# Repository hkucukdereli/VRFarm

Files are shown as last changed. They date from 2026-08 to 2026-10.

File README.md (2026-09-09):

# VRFarm

A behavioural neuroscience rig for head-fixed mice: visual stimuli on a rear-projected
curved screen, capacitive lick detection, calibrated liquid reward, a running wheel,
behaviour video, and photodiode sync — all driven from a browser on the controller.

One rig is two Raspberry Pis. The **Leader** runs the trial loop and every behavioural
device; the **Follower** does nothing but render the projector. The **Controller**
(your Mac/Linux box) hosts two Flask UIs, streams live events, and stores the data.
Rigs are named after cheese.

<p align="center">
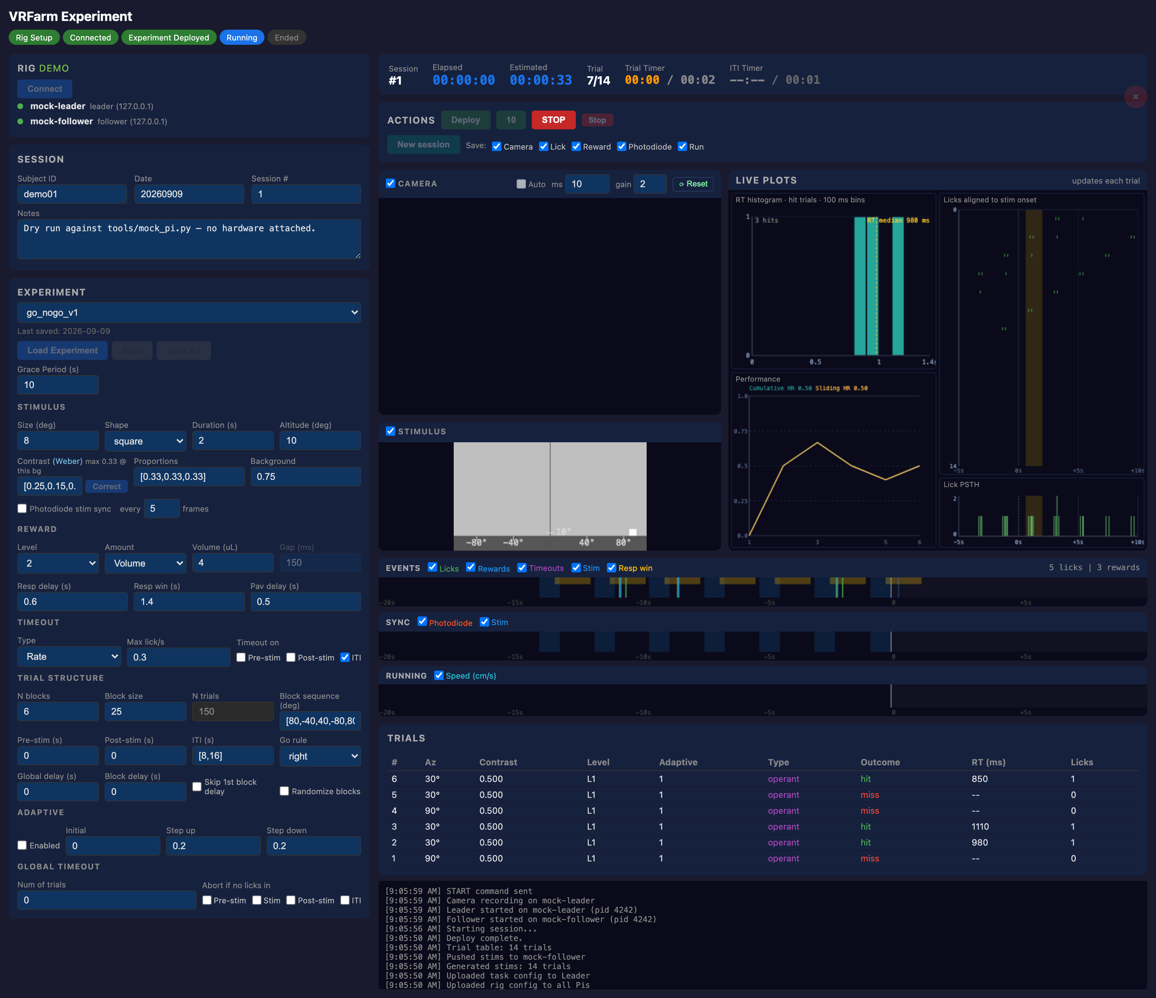
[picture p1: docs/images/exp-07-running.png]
The VRFarm experiment UI during a running session
  
</p>

---

## How it fits together

```
Controller ── controller UI :5000   one app, four tabs: Network · Setup · Experiment · Data
           │                       (build and service rigs, run sessions, watch live, sync data)
                │
                │  REST :5080   deploy code, init devices, camera
                │  UDP  :5572 → START / STOP / REWARD
                │  UDP  :5571 ← trial, lick, reward, stim, sync
                ▼
        Leader Pi ──────────────────────────────────────────────┐
        engine/leader.py: ITI → pre-stim → stim → response       │ UDP :5575
        delay → response window → post-stim, writing HDF5        │ SHOW / QUIT
        lick · reward · camera · photodiode · encoder            ▼
                                                          Follower Pi
                                                    displayd: KMS daemon, renderer
                                                    child draws from a pre-built NPZ
```

Three ideas carry most of the design:

- **Devices are plug-in.** One file in `devices/` declares its I/O type, its packages,
  its tunable parameters and how it writes HDF5. Adding hardware does not touch the engine.
- **Config is split by lifetime.** Hardware facts (pins, calibration, IPs) live in
  `rigs/*.yaml`; the paradigm lives in `experiments/*.yaml`; subject and session are typed
  in at run time. Nothing machine-specific is committed.
- **Stimuli are precomputed.** The Leader builds the whole session's stimulus plan up
  front — geometry warp and luminance correction included — so the Follower only has to
  look up a trial and blit it.

---

## Quick start

Already-built rig, controller already set up:

```bash
conda activate vrfarm
python controller/app.py   # -> http://localhost:5000 (Network / Setup / Experiment / Data)
```

Then, in the Experiment tab: **Load rig → Connect → Load Experiment → fill in
Subject/Date/Session # → Deploy → GO**. At the end of the day the **Data** tab syncs the
sessions off the leaders (Sync Now, or Sync & Poweroff) — see [MULTI_RIG.md](docs/MULTI_RIG.md).
Walkthrough with screenshots:
[Experiment UI](docs/EXPERIMENT_UI.md).

**No hardware?** The whole stack runs on loopback:

```bash
python tools/mock_pi.py     # fake Pi + fake leader
python controller/app.py    # Experiment tab -> Load rig demo -> Connect -> Deploy -> GO
```

**New machine or new rig?** Start at [CONTROLLER_SETUP.md](docs/CONTROLLER_SETUP.md),
then [INITIAL_SETUP_REFERENCE.md](docs/INITIAL_SETUP_REFERENCE.md).

---

## Documentation

| Guide | For |
|---|---|
| **[Docs index](docs/README.md)** | Everything, organised by task |
| [Controller setup](docs/CONTROLLER_SETUP.md) | New controller: network, SSH, conda, data dir |
| [Rig bring-up reference](docs/INITIAL_SETUP_REFERENCE.md) | New/reflashed Pi, envs, GPIO, projector, systemd |
| [Setup UI](docs/SETUP_UI.md) | Defining a rig, deploying code, servicing Pis |
| [Experiment UI](docs/EXPERIMENT_UI.md) | Running a session, live plots, transfer |
| [Experiment protocol](docs/EXPERIMENT_PROTOCOL.md) | Pre-session checks, task parameters, timing |
| [Calibration protocol](docs/CALIBRATION_PROTOCOL.md) | Warp map, luminance, reward valve |
| [Data format](docs/DATA_FORMAT.md) | HDF5 layout and the analysis loaders |
| [Leader wiring](docs/LEADER_WIRING.md) | Pins, 40-pin header map, GPIO rules |
| [Teensy instructions](docs/TEENSY_INSTRUCTIONS.md) | Photodiode sync firmware: build, flash, tune |
| [Rig health monitor](shepherd/README.md) | shepherd: what it watches, thresholds, alerts |

---

## Repo layout

```
controller/    the one controller UI (Flask + SSE)  localhost:5000 — Network / Setup / Experiment / Data
engine/        leader.py (trial loop)                -> runs on the Leader Pi
displayd/      KMS display daemon + renderer child      -> runs on the Follower Pi
devices/       one file per device type + the Device base class
pi_api/        REST API deployed to each Pi (port 5080) + systemd unit
shared/        config loaders, stimulus generator, HDF5 consolidation, notifications
rigs/          rig hardware configs (demo.yaml runs with no hardware)
experiments/   task/paradigm YAMLs
teensy/        photodiode sync firmware (.ino) flashed with arduino-cli
display_calibration/   projector geometry, warp map, luminance fitting
display_diagnostics/   bench tools for the sync square and projector colour
shepherd/      rig health watchdog that runs on a Pi (temperature, disk, CPU, encode rate)
analysis/      HDF5 loaders and analysis notebooks
tools/         mock_pi.py (hardware-free harness) · capture_ui_shots.py (doc screenshots)
docs/          documentation (docs/images generated; docs/assets is local-only)
```

## Requirements

**Controller** — Python 3.11 conda env `vrfarm`:
`flask requests scipy matplotlib numpy h5py pyyaml`

**Pis** — Debian 13 (trixie), conda env `rig` whose Python **must match the system
Python**, because the camera and GPIO bindings are apt-built and symlinked in. GPIO is
`lgpio` (no daemon; works on Pi 4 and Pi 5). Per-device packages are installed for you by
the setup UI's **Install**.

Optional: `VRFARM_SLACK_WEBHOOK` for session start/end/timeout notifications;
`VRFARM_DATA_DIR` to put session data somewhere other than `~/VRFarm/data`.

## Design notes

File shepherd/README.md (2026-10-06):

# shepherd — VRFarm rig health monitor

A tiny, **out-of-process** watchdog that runs on a rig Pi and watches the things
that can silently ruin a session: SoC temperature and throttling, disk space,
CPU/memory, the camera's live encode rate, and whether `pi_api` is still answering.

## Why a separate process

The Pi 5 has **no hardware H.264 encoder and no fan**, so a long session software-
encodes on the CPU and heats up. When it throttles, the encoder slows, **drops
frames, and corrupts the frame timing** the whole camera pipeline exists to
preserve — and none of that is visible in the preview or in the data until you
analyse it. shepherd catches it live.

A monitor living *inside* `pi_api` would freeze at exactly the moment you most
want its data (a thermal stall, a wedged process). shepherd runs in its own
process, so a stall or crash in `pi_api` can't take the watchdog down with it —
and shepherd's API probe is precisely what **detects** that stall.

It is deliberately minimal: each cycle is a few `/proc` and `/sys` reads plus one
short HTTP probe. Sampling cost is far below anything it watches. It **does not
stream telemetry**, does not touch the HDF5, and writes only two plain files.

## What it watches

| Metric | Source | Default warn / critical |
|---|---|---|
| SoC temperature | `/sys/class/thermal` | 50 °C / 70 °C |
| Throttle / under-voltage flags | `vcgencmd get_throttled` | soft-limit / throttling-now |
| Disk used % (video mount) | `statvfs` | 80% / 90% |
| Disk free GB | `statvfs` | 40 / 15 GB |
| Total + per-core CPU | `/proc/stat` | 85% / 95% |
| Memory used % | `/proc/meminfo` | 85% / 95% |
| Disk write rate | `/proc/diskstats` | off by default |
| Camera encode fps (while recording) | `pi_api /api/status` | 45 / 30 fps |
| `pi_api` responsive | HTTP probe | critical once down past the [grace period](#pi_api-grace-period); at once during a session |

Every threshold, direction, and **message** is editable in `~/rig/shepherd/config.yaml` on the leader
(seeded from [`config_template.yaml`](config_template.yaml)).

## Two alert levels

- **warning** → orange in the experiment-UI log
- **critical** → red in the UI log, **and** a Slack message (so it reaches you with
  the browser closed)

One exception: `soc_temp_c` is **muted on the Slack hop only**. A fanless Pi crosses the
70 °C critical routinely under camera encode, so it paged constantly without naming an
action. It still logs to the UI and to `alerts.log` at full level, and the `throttled`
metric — which reports that heat actually cost you frames — still pages. The mute list is
`_SLACK_MUTED_SHEPHERD_METRICS` in `controller/events.py`, i.e. controller-side: no rig deploy needed
to change it.

Alerts are **edge-triggered** — fired when a metric changes level, not every
second — so the log isn't spammed. A still-critical condition re-alerts every
`realert_critical_s` (default 30 s). A return to normal logs a recovery line.

Delivery: a `shepherd_alert` UDP packet to the controller's event port
(`network.event_port`, default 5571). The controller already forwards every event
to the UI over SSE; `controller/events.py` adds the Slack hop for criticals (to that rig's own
webhook) and
`experiment.html` colours the line by level. If no session UI is live the packet is
simply dropped (UDP is best-effort) — criticals still reach Slack.

## Outputs (both under `output_dir`, default `~/shepherd_logs/`)

- `shepherd_<timestamp>.jsonl` — one JSON object per sample (all metrics). A plain,
  separate file; **nothing goes into the session `.h5`.**
- `shepherd_<timestamp>.alerts.log` — human-readable warning/critical/recovery lines.

## Running it

**Installed automatically on the leader.** The setup-UI **Install** deploys
`shepherd.py`, seeds `config.yaml` (see below), and installs + enables + starts the
`shepherd` systemd service. It then runs continuously, learning session state from
the API probe — you do **not** start/stop it per session. Watch it with:
```bash
journalctl -u shepherd -f
sudo systemctl status shepherd
```

**Config is seeded once, then owned by the Pi.** Install copies the repo's `shepherd/config_template.yaml` to
`~/rig/shepherd/config.yaml` with `cp -n` (no-clobber), so thresholds/messages you edit on the leader survive a
re-Install or Deploy. To change them:
```bash
nano ~/rig/shepherd/config.yaml         # on the leader
sudo systemctl restart shepherd         # shepherd reads the file once at startup
```
(The repo only tracks the template. A `shepherd.py` *code* change rides Deploy, and
Deploy restarts shepherd so the change takes effect.)

**Manually (for a quick look or a test):**
```bash
python3 shepherd/shepherd.py --config shepherd/config_template.yaml
python3 shepherd/shepherd.py --config shepherd/config_template.yaml --once   # one sample, then exit
```

## pi_api grace period

Deploy and **Restart API** restart `pi_api` on purpose, and it answers nothing for a few seconds
while systemd respawns it. So `api_health` does not alert on the first failed probe:

- **Outside a session** it waits out a grace period. The controller times every Deploy / Restart
  API restart (`controller/pi_restart.py`) and writes the measured outage ×1.5, kept within
  5–60 s, to `api_grace.json` next to `config.yaml` (through pi_api's `/api/shepherd_grace`).
  shepherd re-reads the file whenever it changes. Until the first timed restart,
  `api_probe.grace_default_s` (10 s) applies.
- **During a session** (the last good probe said the engine was running) it alerts on the first
  failed probe: nothing restarts pi_api on purpose mid-session, and a crash there takes the engine
  with it.

The Deploy log shows both numbers, e.g. `pi_api on cheddar was down 4.1 s` and
`shepherd on cheddar now gives pi_api 6.2 s to come back before alerting`.

## Configuring

Edit `~/rig/shepherd/config.yaml` on the leader and restart shepherd (it reads the file once at
startup). Each metric block:
```yaml
soc_temp_c:
  enabled: true
  direction: high            # 'high' fires when value rises; 'low' when it falls
  warn: 50
  critical: 70
  warn_msg:     "SoC temperature {value}°C — running warm; check ventilation"
  critical_msg: "SoC temperature {value}°C — CRITICAL: thermal throttle imminent"
  recover_msg:  "SoC temperature back to normal ({value}°C)"
```
Message placeholders: `{value}`, `{warn}`, `{critical}`, `{unit}`, `{mount}`
(and `{error}` for `api_health`).

Point the alerts at your controller:
```yaml
shepherd:
  alerts:
    udp: { enabled: true, host: 192.168.10.1, port: 5571 }
```

## Dependencies

stdlib + PyYAML only. The API probe uses `urllib` (stdlib), not `requests`. Runs in
the `rig` conda env with nothing extra to install.

## Notes / limits

- `vcgencmd` and the thermal zones are Pi-only; off a Pi those metrics are simply
  absent (shepherd degrades gracefully, never errors).
- Live encode fps needs `pi_api /api/status` to expose `camera_frames` (added
  alongside this monitor). Older API builds just omit that one alert.
- The disk write-rate meter sums whole-disk devices matching `disk_devices`; it's a
  coarse "is something hammering the disk" signal, off by default.

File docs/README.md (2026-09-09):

# VRFarm documentation

Everything here is task-shaped: find the row that matches what you are trying to do.
Project overview and repo layout are in the [root README](../README.md).

## Start here

| I want to… | Read |
|---|---|
| Set up a **new controller** machine (network, SSH, conda, data dir) | [CONTROLLER_SETUP.md](CONTROLLER_SETUP.md) |
| Bring up a **new or reflashed Pi**, or build a rig from scratch | [INITIAL_SETUP_REFERENCE.md](INITIAL_SETUP_REFERENCE.md) |
| Understand the **two UIs** before touching anything | [SETUP_UI.md](SETUP_UI.md) · [EXPERIMENT_UI.md](EXPERIMENT_UI.md) |

## Run experiments

| I want to… | Read |
|---|---|
| Run a session end to end, and know what to check first | [EXPERIMENT_PROTOCOL.md](EXPERIMENT_PROTOCOL.md) |
| Find a button, or work out why one is greyed out | [EXPERIMENT_UI.md](EXPERIMENT_UI.md) |
| Understand reward levels, timeouts, task YAML fields | [EXPERIMENT_PROTOCOL.md § Task Parameters](EXPERIMENT_PROTOCOL.md#task-parameters) |
| Load and analyse the data afterwards | [DATA_FORMAT.md](DATA_FORMAT.md) |

## Maintain the rig

| I want to… | Read |
|---|---|
| Add a device, change pins, deploy code, service a Pi | [SETUP_UI.md](SETUP_UI.md) |
| Calibrate the reward valve, projector geometry, or luminance | [CALIBRATION_PROTOCOL.md](CALIBRATION_PROTOCOL.md) |
| Look up geometry parameters | [display_calibration/geometry_params.md](../display_calibration/geometry_params.md) |
| Check wiring, pins and the 40-pin header map | [LEADER_WIRING.md](LEADER_WIRING.md) |
| Build, flash or tune the **Teensy** photodiode sync firmware | [TEENSY_INSTRUCTIONS.md](TEENSY_INSTRUCTIONS.md) |
| Watch rig health during a session (temperature, disk, encode rate) | [shepherd/README.md](../shepherd/README.md) |

## Map of the system

```
Controller  (controller/app.py :5000 — Network / Setup / Experiment / Data tabs)
  │  REST 5080  ─ deploy, config, device init, camera
  │  UDP  5572 →  START / STOP / REWARD
  │  UDP  5571 ←  trial, lick, reward, stim, sync events
  ▼
Leader Pi (engine/leader.py) ── trial loop + lick, reward, camera, photodiode, encoder
  │  UDP 5575 → SHOW / QUIT
  ▼
Follower Pi (displayd) ── KMS daemon; renderer child is sole DRM master on the DLP projector
  │  UDP 5573 → stim_onset / hb_flash acks, display_health
  ▲
```

## Conventions

- **Rig YAML** (`rigs/*.yaml`) holds hardware facts: pins, I²C addresses, calibration
  tables, Pi roles and IPs, ports. Edited in the setup UI.
- **Task YAML** (`experiments/*.yaml`) holds the paradigm in four sections — `stimulus`,
  `reward`, `session`, `adaptive`. Edited in the experiment UI.
- **Machine-specific paths** are never in YAML: the controller data root comes from
  `$VRFARM_DATA_DIR`, else `~/VRFarm/data`.
- All timestamps are `time.time()` Unix seconds, NTP-synced across all three machines.

## Screenshots

UI images live in `docs/images/` and are generated, not hand-taken:

```bash
python tools/capture_ui_shots.py            # all of them
python tools/capture_ui_shots.py --only exp-07
```

The script starts `tools/mock_pi.py` and both UIs on loopback and drives them with
Playwright (`pip install playwright && playwright install chromium`). Re-run it after any
UI change so the docs do not drift. Shots needing real hardware — a live camera frame, the
projector, the geometry landmark tool — must still be taken on the rig.

> `docs/assets/` is a **local-only** stash (audits, hardware design notes, vendor manuals)
> and is gitignored — nothing in the tracked docs links to it.

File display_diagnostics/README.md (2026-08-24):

# display_diagnostics — projector / photodiode bring-up tools

Standalone optical diagnostics for the **follower / display Pi** (mozzarella). They drive
the projector directly so you can check the display→photodiode→scope path and DLP colour
before trusting the real sync pipeline. **pygame**, mirroring `devices/display.py`'s
fullscreen setup by copy — no UDP, no engine, no devices framework, they write no data.
These are kept (not scratch): re-run them on the next rig bring-up. Sibling of
`display_calibration/` (geometry/warp), which owns the calibration side.

The photodiode itself is a GPIO input on **cheddar** (leader, GPIO24) — `devices/photodiode.py`.
These tools only exercise the *optical* side (display → photodiode → your scope); tape the
diode over the sync patch.

## Tools

| File | What it does |
|---|---|
| `sync_square_flash.py` | Flashes the red sync square (matches `display._draw_sync_square`): steady or per-frame pulse, single bottom-centre patch or a bottom-row sweep, colour compare. Photodiode bring-up + mounting-spot sweep. |
| `dlp_color_test.py` | Pushes full-frame / split solid colours (R/G/B/dark, left-right splits) — DLP colour-wheel / brightness-uniformity check. |
| `run_sync_flash.sh` | scp `sync_square_flash.py` to mozzarella and run it on kmsdrm (put displayd in STANDBY first: `curl -sX POST :5581/standby`). Args pass straight through. |

## sync_square_flash.py

Cycles `[ 10 s blank ] → [ 5 s stim ] → repeat`. During the stim it draws a centre stimulus
square plus the red sync square; during the blank both are background gray. Every stim ON/OFF
edge prints a `time.time()` stamp so you can line the scope trace up to the software clock.

**Layout** — `--row N`: by default one red square at bottom-center (matches the real rig).
`--row N` instead draws N evenly-spaced red squares edge-to-edge along the bottom (first
flush-left, last flush-right, so the corners are included), numbered on screen and all pulsing
together. Sweep the diode along the row to choose a mounting spot and to check DLP brightness /
color-wheel uniformity across the screen width.

**Timing** — two modes:

| mode | flag | what the patch does |
|---|---|---|
| steady (default) | — | red for the whole 5 s stim → one rising + one falling edge per cycle |
| pulse | `--pulse N` | replicates the real per-frame sync (`follower._show_synced`): patch ON every Nth frame during the stim. At 60 Hz, `--pulse 5` ≈ a 12 Hz, 1-frame-on train |

### Run it

Projector X must be up (`start_projector.sh` on mozzarella; `run_sync_flash.sh` runs it if needed).

From the Mac:

```bash
cd display_diagnostics
./run_sync_flash.sh --row 7              # bottom-row sweep: 7 squares, find the diode spot
./run_sync_flash.sh --row 7 --pulse 5    # sweep with the real per-frame cadence
./run_sync_flash.sh                      # single bottom-center square (matches the real rig)
./run_sync_flash.sh --color white        # compare red vs white edge on the scope
./run_sync_flash.sh --blank 8 --stim 4 --cycles 5
```

Or directly on mozzarella:

```bash
SDL_AUDIODRIVER=dummy /usr/bin/python3 sync_square_flash.py
```

`ESC` / `q` / `Ctrl-C` quits.

### Options (`sync_square_flash.py --help`)

`--blank` (10) · `--stim` (5) · `--pulse` (0=steady) · `--row` (0=single) · `--no-labels` ·
`--color` red/white/green/blue · `--sync-size` (40) · `--stim-size` (200) ·
`--contrast` (1.0) · `--bg-gray` (0.0) · `--res` (1920 1080) · `--refresh` (60) ·
`--cycles` (0=forever)

## dlp_color_test.py

Loops a pipe-separated colour sequence — each block is `SPEC,...:COUNT`, where SPEC is a full
colour (`red`) or a left/right split (`red/black`) and COUNT is `N` frames or `Ns` seconds.
Default: full R, G, B, dark (1 s each), then half-R, half-G, half-B. Use it to eyeball DLP
colour-wheel behaviour and brightness uniformity.

```bash
SDL_AUDIODRIVER=dummy /usr/bin/python3 dlp_color_test.py
... dlp_color_test.py --seq "red:1s | red/black:1s"   # full then split
... dlp_color_test.py --cycles 20                     # stop after 20 loops
```

Headless projector, so to stop a backgrounded run: `pkill -9 -f 'dlp_color_test[.]py'`.

## Colour note (background)

The real sync square is **red** (`display._draw_sync_square` → `(255,0,0)`). A broadband
photodiode over a red patch on a mid-gray background sees a *smaller* flux change than it looks
(red sums to 255 vs gray's 381), and on a DLP the single red channel is chopped by the colour
wheel — so the edge can read weak or even inverted. **This was resolved:** `devices/display.py`
now draws the sync pulse **red-on-BLACK** (`display.py` `_show_synced` / the forced pre-warp
patch), which triggers reliably. To reproduce that here, run `sync_square_flash.py --bg-gray -1`
(black background). `--color white` is still handy to sanity-check the scope against a maximal edge.

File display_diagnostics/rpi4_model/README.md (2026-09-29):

# Raspberry Pi 4 B + Joy-IT Armor Case "BLOCK" — simplified 3D model

The follower Pi as it sits on the rig: a Raspberry Pi 4 Model B inside the Joy-IT passive
aluminium cooler **RB-AlucaseP4+07 "Armor Case BLOCK"** (finned top block + bottom plate, four
M2.5 socket-head screws from below). Boxes and cylinders only; the board, its four holes and all
connector positions are exact from the Raspberry Pi drawing, the case envelope is Joy-IT's, and
the case details are estimated from photos and flagged below.

| File | What |
|---|---|
| `rpi4b_joyit_armor_case_simplified.step` | assembly STEP, one named solid per part |
| `rpi4b_joyit_armor_case_simplified.stl` | mesh |
| `rpi4b_joyit_armor_case_simplified_iso.svg` | isometric line drawing |
| `rpi4b_joyit_armor_case_hole_maps.png` | top view and stack-up side view with the holes |
| `rpi4_armor_case_dims.py` | **the numbers**, with a `CASE_ESTIMATED` block to check with calipers |
| `build_model.py`, `plot_hole_maps.py` | CadQuery build, matplotlib drawing |

## Frame

Raspberry Pi drawing convention: **X** along the 85 mm edge, 0 at the microSD end, 85 at the
USB/Ethernet end · **Y** along the 56 mm edge, 0 at the USB-C/HDMI/audio edge, 56 at the GPIO
edge · **Z** up, 0 = PCB bottom, 1.4 = PCB top. Envelope about 90 × 57 × 27 mm including the
microSD card, the USB/Ethernet overhang and the estimated 3 mm gap under the block.

## Holes

The assembly has exactly four fixing points: the Pi's mounting holes. Both case halves use them.

| # | Type | Position (X, Y) | Used by |
|---|---|---|---|
| 4 | Ø2.7 through the PCB (M2.5 clearance), 58 × 49 pattern, 3.5 from the edges | (3.5, 3.5), (61.5, 3.5), (3.5, 52.5), (61.5, 52.5) | Joy-IT M2.5 socket-head screws from below, through the bottom plate and the PCB, into threaded posts in the top block |

No other hole is published for either case half. To mount the cased Pi, replace the four screws
with longer M2.5 screws through your bracket under the 3.5 mm bottom plate, or clamp the plate.
Confirm on the part that the plate has no extra holes before designing around that.

## Exact vs estimated

**Exact (Raspberry Pi mechanical drawing):** outline 85 × 56, corner radius 3.0, holes, connector
centres (USB-C x 11.2, micro-HDMI x 26.0 and 39.5, Ethernet y 45.75, USB stacks y 27 and 9, GPIO
header centre x 32.5), component heights above the board (USB-C 3.2, HDMI 3.0, audio 6.0, header
8.5, Ethernet 13.5, USB 16.0, SoC 2.4, FPC connectors 5.5). Connector protrusion past the board
edge is a typical value, ±0.5 mm.

**Published by Joy-IT:** top block 69 × 56 × 15.5, bottom plate 87 × 56 × 7.5, 107 g, CNC-milled
aluminium, four screws, allen key, thermal pads.

**Estimated from photos, measure before relying on it** (`CASE_ESTIMATED` in the dims file):
the block starts at the microSD edge and stops at x = 69, leaving the USB/Ethernet end open; block
underside 3.0 mm above the PCB top; ten grooves along X, 5.0 mm pitch, 2.6 wide, 9 deep; an open
slot over the GPIO header (x 6.5…58.5) and a slot over the camera connector; a pocket along the
front edge clearing the audio jack; Ø6 threaded posts at the holes; bottom plate 3.5 thick with
Ø6 × 4.0 bosses; M2.5 × ~25 socket-head screws with counterbored heads.

If the case on the rig is the closed **RB-AlucaseP4+08** box (91 × 65 × 34, cast, milled channels)
instead, say so: it is a different model, not a parameter change.

## Regenerate

```bash
~/cadenv/bin/python build_model.py            # same venv as ../projector_model (pip install cadquery)
conda activate vrfarm && python plot_hole_maps.py
```

## Sources

- Raspberry Pi 4 Model B mechanical drawing, `datasheets.raspberrypi.com/rpi4/raspberry-pi-4-mechanical-drawing.pdf`
- Joy-IT RB-AlucaseP4+07 product page, datasheet (published 2020-02-11) and manual, `joy-it.net/en/products/RB-AlucaseP4+07`

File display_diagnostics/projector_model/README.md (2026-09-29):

# DLPDLCR230NPEVM — simplified 3D model and hole map

A simplified, parametric model of the projector every VRFarm follower drives: the TI **DLP
LightCrafter Display 230NP EVM** (formatter board DLP038 + Young Optics FLA12-F engine on TI's
sheet-metal base). Boxes and cylinders only, but every part sits at TI's coordinates and every
screw hole is at TI's position, diameter and type. Made for designing mounts and enclosures.

| File | What |
|---|---|
| `dlpdlcr230npevm_simplified.step` | assembly STEP, one named solid per part, coloured |
| `dlpdlcr230npevm_simplified.stl` | the same as a mesh (viewers, slicers) |
| `dlpdlcr230npevm_simplified_iso.svg` | isometric line drawing |
| `dlpdlcr230npevm_hole_maps.png` | 2D hole maps: bottom, top, back wall, side wall |
| `dlpdlcr230npevm_dims.py` | **the numbers** — every dimension and hole, with what it is for |
| `build_model.py` | CadQuery script that builds and exports the model |
| `plot_hole_maps.py` | matplotlib script for the PNG |

## Frame

TI's own "DLP038" assembly frame, so the numbers can be checked against TI's files:
**X = depth** (lens points to −X, lens front at X = −15.37) · **Y = up** (the assembly stands on
Y = −4.82; PCB top at Y = 32.85) · **Z = width** (40-pin header along the −Z edge). For a Z-up CAD
system rotate −90° about X. Envelope **87.4 (X) × 48.2 (Y) × 81.4 (Z) mm**, matching TI's
assembly drawing (81.40 × 87.96 × 48.17).

## Holes, by part

Threads are listed as TI tapped them; the model draws them at tap-drill size (M1.6 → Ø1.25,
M2 → Ø1.60, M2.5 → Ø2.05), exactly as TI's STEP does. "CSK" = Ø2.90 through + Ø5.50 × 90°
countersink for an M2.5 flat-head screw.

**There is no dedicated external mounting hole on this EVM.** Every hole below is used by a TI
fastener. Bottom-side candidates for a rig mount are the three base tabs (occupied by flat-head
screws you can replace with longer ones), the bracket's wall edges (clamp), or the tapped M2.5/M2
wall holes (occupied; replace screws).

### MCH051 base (1.63 mm aluminium sheet, footprint 69.82 × 77.31, standing plane Y = −4.82)
| # | Type | Axis | Position (mm) | TI use |
|---|---|---|---|---|
| 3 | Ø2.90 through, Ø5.50 90° CSK opening **downward** | Y | (X, Z) = (3.50, 4.77), (51.81, −23.95), (62.31, −23.95) | M2.5 × 5 flat-heads from below into the fan-bracket tab (2) and the PCB corner standoff (1) |
| 4 | M2.5 × 0.45 tapped, horizontal | X / Z | back wall X≈70: (Y −0.82, Z −23.95); −Z wall Z≈−63.9: X 12.64 and 57.27 at Y −0.82; +Z wall Z≈13.4: X 57.27 at Y −0.82 | formatter-base wall screws (M2.5 × 5 flat-heads, CSK on the bracket) |
| 3 | M1.6 × 0.35 tapped | Y | (10.76, −42.42), (39.06, −39.72), (39.06, −15.22) | engine to base (M1.6 × 12 socket heads) — table only, inside the simplified cutout |

### MCH053 formatter base (2.05 mm L-bracket, 78.10 × 81.40, walls Y −4.82…22.83, flange top Y = 24.88)
| # | Type | Axis | Position (mm) | TI use |
|---|---|---|---|---|
| 3 | M2.5 × 0.45 tapped, top flange | Y | (X, Z) = (3.50, −35.50), (16.84, −60.26), (60.40, −51.74) | PCB: M3 6 mm spacer + M2.5 × 10 screw |
| 2 | M2 × 0.4 tapped, top flange | Y | (49.11, 3.73), (66.11, 3.73) | PCB: M3 5 mm spacer + M2 × 12 screw |
| 6 | M2 × 0.4 tapped, walls, all at Y = 20.46 | X / Z | back wall: Z 1.37, −51.92 · front short wall: Z −48.25 · −Z wall: X 57.28, 12.62 · +Z short wall: X 57.28 | (TI: 8× M2 total with the two above) |
| 4 | Ø2.90 + Ø5.50 CSK on the **outer** face, all at Y = −0.80 | X / Z | back wall: Z −23.96 · −Z wall: X 57.28, 12.62 · +Z short wall: X 57.28 | M2.5 × 5 flat-heads into the base's tapped wall holes |

### MCH052 fan bracket (1.63 mm) — fan 25 × 25 × 10 at X 44.5…69.6, Z −42.1…−32.0
| # | Type | Axis | Position | TI use |
|---|---|---|---|---|
| 4 | M2 × 0.4 tapped | Z | (X, Y) = (57.07 ± 10, 9.76 ± 10), 20 × 20 pattern, Ø24 bore | fan screws |
| 2 | M2.5 × 0.45 tapped, bottom tab | Y | (X, Z) = (51.81, −23.95), (62.31, −23.95) | under the base's two CSK holes |

### DLP038 PCB (70.00 × 72.76 × 2.04, at Y 30.81…32.85, X 0…70, Z −63.73…9.03)
| # | Type | Position (X, Z) | Support underneath |
|---|---|---|---|
| 4 | Ø2.69 (M2.5 clearance) | (3.50, −35.50), (16.84, −60.26), (60.40, −51.74) | M3 6 mm spacers on the flange |
| | | (3.50, 4.77) | M2.5 × 23 hex + M2.5 × 10 M-F standoff column down to the base tab |
| 2 | Ø2.39 (M2 clearance) | (49.11, 3.73), (66.11, 3.73) | M3 5 mm spacers on the flange |

40-pin header J2: X 63.97…69.05, Z −62.85…−12.05 (pin rows at X 65.24 / 67.78, 2.54 pitch), 8.5 mm
tall. Barrel jack: X 0.94…12.94, Z −61.20…−45.95.

### Young Optics FLA12-F engine (body 33.28 × 23.07 × 53.03 at X 7.19…40.46, Y −2.97…20.09, Z −45.90…7.12)
Lens axis at (Y 10.39, Z −11.32), barrel Ø16.9, front hood 30.3 × 15.5 reaching X = −15.37.
Top plate per TI's Figure 5-1 (34.13 × 54.99): **4× Ø1.66** (M2 thread-forming; TI uses M2 × 12
pan heads) at plate coordinates (3.63, 3.54), (31.42, 6.24), (31.42, 30.73), (7.53, 50.64).
The plate's orientation in the assembly frame is inferred (v = 0 at the engine's +Z end); check
against the unit before relying on those four positions. All other holes above are exact.

## Provenance

- **TI TIDM757**, "CAD/CAE Symbol" download on the [TIDA-080009](https://www.ti.com/tool/TIDA-080009)
  page: `DLP038_Mechanical_092420.zip` with MCH051/052/053 drawings and STEP files and the full
  `DLP038 - REVF.STEP` assembly. Positions here were measured on the STEP cylinder faces.
- **TI TIDM755**, assembly drawing "P23 EVM TOP ASSEMBLY" DLP038 rev F (2020-09-24): envelope and
  the fastener BOM quoted in `dlpdlcr230npevm_dims.py`.
- **TI DLPU103B**, DLP LightCrafter Display 230NP EVM User's Guide, Figure 5-1: engine drawing.

TI's files are licensed for use in development with TI parts and may not be redistributed, so
they are **not** in this repo — download them from the link above. The 81 × 87 mm "business card"
size on TI's product page is the bracket footprint, not the PCB (70.00 × 72.76).

## Regenerate

```bash
python -m venv ~/cadenv && ~/cadenv/bin/pip install cadquery      # ~1.8 GB, once; keep out of vrfarm
cd display_diagnostics/projector_model
~/cadenv/bin/python build_model.py                                # STEP + STL + SVG
conda activate vrfarm && python plot_hole_maps.py                 # PNG
```
Edit numbers only in `dlpdlcr230npevm_dims.py`; both scripts read from it.

## Simplifications

Sheet-metal bends, reliefs and slots, the base's exact tab outlines, the DMD flex tab, LED cables,
the FPD-Link connector and small components are omitted. Walls and flanges are full-length boxes.
The engine is a box with the lens barrel and the three LED heat sinks; its internal features are not
modelled.

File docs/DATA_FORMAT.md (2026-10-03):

# VRFarm session data format

**`format_version: 2`** — a transferred session is **one self-contained HDF5 file** plus the raw video.

```
<dest>/<subject>/<subject>_<date>/<session_id>/
├── <session_id>.h5     # everything: trials, running wheel, stimulus plan, per-device data, camera timestamps, metadata
└── video.h264          # raw H.264 elementary stream (only if the camera was saved)
```

`session_id = <subject>_<YYYYMMDD>_<NNN>` (e.g. `mouse1_20260803_001`). `<dest>` is the Browse override, else `$VRFARM_DATA_DIR`, else `~/VRFarm/data`.

---

## How the file is built (at session end)

During a run the Leader writes a **flat** `.h5` (one dataset per field at the root), and the camera/stim generator drop sidecars alongside it:

| sidecar | written by |
|---|---|
| `metadata.yaml` | leader engine (in `_finalize_session`) |
| `stimuli.npz` | stim generator |
| `trials.yaml` | stim generator (human-readable copy of the NPZ) |
| `frame_timestamps.npy` | camera (on the SSD, next to `video.h264`) |

**Consolidation runs at session end, not at Transfer.** The moment the session stops or finishes, the Leader engine's `shutdown()` calls `_consolidate_at_exit()` — after every device is closed and its sidecar flushed (the camera's `frame_timestamps.npy` included) — which runs [`shared/consolidate.py`](../shared/consolidate.py) on the just-closed `.h5`. So the archive is already self-contained before anything is transferred. **Transfer re-POSTs `/api/consolidate/<session_id>` as a no-op safety net**, so a session whose exit consolidation didn't run (crash, hard stop) still gets consolidated when pulled.

`consolidate.py`:

1. Reorganizes the flat root datasets into groups (`/trials`, `/lick`, `/reward`, `/photodiode`). Any dataset not in its map — **including the running-wheel arrays** — falls through to `/trials`.
2. Folds `metadata.yaml` into **root attributes**.
3. Folds `stimuli.npz` into **`/stimulus`**, dropping fields already recorded in `/trials` (no redundancy).
4. Folds `frame_timestamps.npy` into **`/camera/frame_timestamps`**.
5. Deletes all four sidecars (`trials.yaml` is redundant with the NPZ).

It's **idempotent** (a file already at `format_version 2`, or that already has a `/trials` group, is left alone) and **atomic** (writes a temp file, then swaps). Only `<session>.h5` + `video.h264` are then pulled to the controller.

---

## File structure

```
<session_id>.h5
├─ (root attrs)          session metadata + full task_config
├─ /trials/              recorded per-trial columns + the continuous running-wheel stream
├─ /stimulus/            pre-generated plan (per-trial arrays + scalar group-attrs)
├─ /lick/                (only if lick_sensor was saved)
├─ /reward/              (only if reward was saved)
├─ /photodiode/          (only if photodiode was saved)
└─ /camera/              (only if the camera was saved)
```

### Root attributes — session metadata
| attr | notes |
|---|---|
| `session_id`, `subject_id`, `date`, `session_num`, `notes` | session identity |
| `level`, `rig_name`, `timestamp` | paradigm level, rig, Unix time of finalize |
| `n_trials_completed`, `n_trials_planned` | trial counts |
| `saved_devices`, `skipped_devices` | which devices' detailed data was recorded. `camera` moves to `skipped_devices` when `camera_saved` is false; sessions recorded before that flag existed list `camera` as saved even when no video was taken |
| `camera_requested`, `camera_saved` | bools sent by the controller at START: Camera was checked at GO / the camera Pi confirmed recording started. **Absent = unknown** (sessions before these existed). A session with `camera_saved: true` and no video on the leader shows as **missing** in the Data tab and is never purged |
| `task_config` | **the entire task YAML as a JSON string** — full paradigm reconstruction |
| `format_version` | `2` |

### `/trials/` — recorded per-trial data (length = `n_trials_completed`)
| dataset | dtype | meaning |
|---|---|---|
| `trial_num`, `block_num` | i4 | indices |
| `trial_outcome` | str | `"hit"` / `"miss"` |
| `level_effective` | f4 | level actually run (adaptive 2.5 → the drawn 2 or 3) |
| `adaptive_state` | f4 | P(L3) for adaptive 2.5, else 1 |
| `stim_az_deg` | f4 | stimulus azimuth (as run) |
| `contrast` | f4 | raw value in the configured metric (what the UI showed) |
| `corr_contrast` | f4 | stimulus **brightness** rendered (0..1 of the intensity calibration's uniform range; may exceed 1). Before the light model (2026-10) it was the normalized headroom fraction |
| `iti_duration_s` | f4 | **actual** ITI before this trial |
| `iti_start_t`, `stim_onset_t`, `true_onset_t`, `response_window_t`, `outcome_t`, `first_lick_t` | f8 | event times (Unix s, NTP-synced) |
| `display_latency_s` | f8 | `true_onset_t − stim_onset_t` (photodiode-measured) |
| `sync_ok` | i1 | 1 if the online photodiode onset-sync landed that trial |
| `trial_run_distance_cm` | f4 | distance the running wheel turned during this trial (cm) |

`true_onset_t` is the display onset corrected by the photodiode; `stim_onset_t` is when the Leader sent SHOW.

#### Running-wheel stream — also under `/trials/`, but length = **number of encoder samples**, not per-trial
The AS5600 wheel encoder is a *continuous* device: it streams for the whole session, so these arrays are far longer than the per-trial columns above (tens of thousands of samples). They share the `/trials` group only because the engine writes them as root datasets and they fall through `consolidate.py`'s group map. They are **not** part of the per-trial `Session.trials` table (different length) — read them from `Session.running` (see Loading) or h5py directly.

| dataset | dtype | meaning |
|---|---|---|
| `running_t` | f8 | sample time (Unix s, NTP-synced — same timebase as `/trials` events) |
| `running_counts` | i8 | **cumulative signed raw encoder counts — the ground truth.** 4096 counts/rev (12-bit AS5600); rotations = `counts / 4096` |
| `running_distance_cm` | f4 | cumulative distance = rotations × wheel circumference (π · `wheel_diameter_cm`) |
| `running_speed_cms` | f4 | instantaneous speed = d(distance)/dt |

Because `running_counts` is the raw ground truth, **speed and distance can be fully recomputed offline** — even with a corrected wheel diameter.

### `/stimulus/` — the pre-generated plan (de-duplicated vs `/trials`)
Per-trial arrays (length = `n_trials_planned`), plus block arrays:
| dataset | meaning |
|---|---|
| `stim_alt_deg` | stimulus altitude/elevation |
| `px_x`, `px_y`, `px_size` | on-screen pixel position + size |
| `duration_s` | planned visual stimulus duration |
| `prestim_s`, `poststim_s` | planned pre/post-stim periods |
| `iti_planned_s` | planned ITIs (length n+1: leading + between + trailing) |
| `block_delays`, `block_start_indices` | per-block delay + first-trial index |
| `stim_brightness`, `stim_lum` | stimulus brightness and requested light (calibration units) |
| `stim_drive`, `contrast_measured` | drive at the stimulus centre; contrast of light delivered there (after any clipping) |

Scalar params as **group attributes**: `background_gray` (a brightness), `bg_lum` (its light), `intensity_calibration` (file whose light model was used), `light_unit`, `shape`, `global_delay`, `block_delay_skip_first`, `sync_square_every_n`.

> Dropped as redundant with `/trials` (recorded): `trial_idx`, `block_num`, `stim_az_deg`, `contrast`, `corr_contrast`, `bg_gray`, `n_trials`.

### `/lick/`, `/reward/`, `/photodiode/` — per device (present only if saved)
| group | datasets |
|---|---|
| `/lick/` | `lick_times` (vlen f8, in-trial), `iti_lick_times` (vlen f8), `iti_lick_count` (i4) |
| `/reward/` | `reward_t` (f8), `reward_amount_ul` (f4, commanded µL), `reward_pavlovian` (i1, 1 = Pav-delay rescue) |
| `/photodiode/` | `sync_pulses` (vlen f8 — rising-edge times) |

Unchecked (skipped) devices → their group is simply **absent** (see `skipped_devices`). Core `/trials` data is always written. The running-wheel **encoder has no group of its own** — its per-trial and continuous data live under `/trials` (above).

### `/camera/frame_timestamps` — video frame timing (present only if saved)
`N×3` float64, with a `columns` attribute:
| column | meaning |
|---|---|
| `frame_idx` | index into the `video.h264` frames |
| `wall_clock_s` | host wall clock at frame callback (`time.time()`, NTP-synced — **same timebase as all `/trials` events**) |
| `sensor_ts_ns` | hardware `SensorTimestamp` (start of readout) on `CLOCK_BOOTTIME`, ns |

---

## Loading (`analysis/loaders.py`)

Two classes turn the file into tidy pandas DataFrames: **`Session`** (one file) and **`Dataset`** (many, concatenated). Every frame carries `session_id` + `subject_id` columns, so single- and multi-session frames are interchangeable.

```python
from analysis.loaders import Session, Dataset

s = Session(session_dir)          # a session dir OR the .h5 path
s.trials      # one row / completed trial — the analysis-ready wide table (see below)
s.running     # one row / wheel-encoder sample (continuous stream; + rotations column)
s.licks       # one row / lick   (long form: in-trial + ITI, times rel. to onset/window)
s.pulses      # one row / photodiode sync pulse (long form, times rel. to onset)
s.stimulus    # one row / planned trial
s.camera      # one row / recorded video frame (empty if the camera wasn't saved)
s.meta        # dict of root attrs; s.meta["task_config"] is the full paradigm
s.stim_attrs  # scalar /stimulus attrs + block arrays (block_delays, iti_planned_s, …)

ds = Dataset(".../data/HK1")      # dir (recursive *.h5), glob, list of paths, or Session(s)
ds.trials                          # every session's trials stacked, tagged by session_id
ds.add(".../HK1_20260811_001.h5")  # append another session (chainable)
ds.meta                            # one row per session
```

**`s.trials` columns** = the recorded `/trials` per-trial cols, plus merged per-trial device data, planned `/stimulus`, and derived ready-to-plot columns:
- **merged:** `reward_t`, `reward_ul`, `pavlovian`, `n_licks`, `n_iti_licks`, `iti_lick_count`, `n_pulses`, `first_pulse_t`, `trial_run_distance_cm`, and planned `stim_alt_deg`, `px_x/px_y/px_size`, `duration_s`, `prestim_s`, `poststim_s`.
- **derived:** `latency_ms`, `rt_ms` (first lick − response-window open), `reward_lat_ms` (reward − true onset), `first_pulse_lat_ms`, `hit` (bool).

The continuous running-wheel arrays are **not** in `s.trials` (different length) — they're in `s.running`. **Only format_version 2 is supported** (no legacy `.npz`/flat-HDF5 fallback).

---

## Not in the session folder
- **Subject index** `subjects/<subject>.json` (controller-side, at the default data dir) — a running log across the subject's sessions (session_id, date, level, trial counts, block sequence, stim size, contrast values, notes). Written once per transfer.

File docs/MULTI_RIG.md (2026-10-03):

# Multi-rig controller

**Last updated:** 2026-09-08

One controller (the lab's is `fystyk`, an Ubuntu box) runs several rigs from one web app on one port. This page explains what
changed from the two old apps (`app/` experiment UI and `setup/` setup UI), how the four
tabs work, and what the Data tab does to your files.

```bash
conda activate vrfarm
python controller/app.py            # http://localhost:5000  (--port 5055 if macOS AirPlay owns 5000)
```

## The four tabs

- **Network** — the rigs and their Pis. Add a rig (the next free IP pair is suggested:
  .101/.102, .103/.104, …), edit Pi names / IPs / roles / users / devices, rename or delete a
  rig (the YAML moves to `rigs/.trash/`), check every Pi over SSH and the REST API, and make
  **groups** ("super rigs"): a group loads all its rigs at once from the Load menu of Setup and
  Experiment and from the Data tab. The architecture diagram is drawn from the rig YAMLs.
- **Setup** — one sub-tab per loaded rig, each the familiar setup page: Pi cards (Check /
  Install / Deploy / Restart API / Reboot / Shutdown), the device catalog and device cards,
  calibration, Slack and Monitor toggles, Save Rig. Pi identity is edited in Network, not here.
- **Experiment** — one sub-tab per loaded rig, each the familiar experiment page. "Load Rig"
  became **Connect** (still a button: connecting stops leftover processes and re-initializes
  devices on the Pis). Transfer is gone; **New session** returns an ended rig to Connected.
  The Save checkboxes (Camera, Lick, Reward, Photodiode, Run) stay.
- **Data** — syncing, purging and powering off, over SSH only (see below).

Hidden sub-tabs keep running (trial counters keep updating) but pause their camera stream; the
badge on each sub-tab shows the phase, trial count and hit rate. Closing a rig in both Setup
and Experiment unloads it from the controller.

## Do rigs need different ports? No.

The ports on the Pis (5080, 5572, 5573, 5575, 5581, 5582) are opened on each Pi separately, so
four rigs with the same numbers never clash. On the controller only one port is opened, UDP 5571,
once at start-up. Every datagram is sorted by the sender's IP to the rig whose Pi has that IP;
as a backup every leader event also carries a `rig` field (that is how the mock Pis, all at
127.0.0.1, are told apart in the tests). The only thing that must be unique per rig is the IP
pair. Datagrams nobody owns are counted and shown at the bottom of the Network diagram.

## Addresses and switch capacity

Everything shares one flat subnet, `192.168.10.0/24`, with no VLANs:

| Range | Use |
|---|---|
| `.1` | the controller (`controller_ip` in `controller.yaml`; new pairs are derived from its /24) |
| `.101`–`.250` | rig IP pairs from **Add rig**: leaders `.101, .103 … .249`, follower = leader + 1 |
| `.251`–`.254` | infrastructure, never suggested — the switch's web UI is **`.254`** |

The suggester only checks the rig YAMLs, so nothing that isn't a rig may use `.101`–`.250`.

The switch is a **Zyxel XGS1210-12**: 8×1G + 2×2.5G RJ45, 2×10G SFP+. The controller sits on one
SFP+ port over a DAC; the other is reserved. That leaves **10 RJ45 ports, i.e. 5 rigs of two Pis**.
For more, chain a second switch on the spare SFP+ port — 10G between switches, so the uplink
doesn't become the bottleneck — and give it `.253`.

Why the controller link is 10G: the Data tab syncs up to `parallel_rigs` leaders at once, each at
its Pi's 1G. On a 1G controller port those syncs would saturate the one link that every *running*
rig's UDP also crosses. The per-rig guard skips only the rig being synced, not its neighbours.

## The Data tab

Load a rig or a group. Each rig gets a card with a checkbox (which rigs the buttons act on),
the leader's SSH status, hostname, whether the experiment engine is running, free disk on the
data drive and the video SSD, and the list of **date folders** (`<mouse>/<mouse>_<date>`):

- **green** — every tree that holds the folder (data dir, video dir) has nothing left to copy in a
  strict rsync dry run, and no session that recorded video is missing it
- **red** — something is still pending
- **missing** (red, "video missing") — a session recorded `camera_saved: true` but its video is not
  on the Pi. Never purged, and Sync & Poweroff leaves the rig on
- **grey** — the check can't be trusted: no SSH, a dry run failed (hover the folder for why), the
  video drive is not mounted (`data.video_mount`), or the leader needs a Deploy

No nonzero rsync exit counts as clean — exit 23 is also what an unreadable subdirectory gives. A
folder labelled **no video** is normal: the camera was unchecked for those sessions (see
[Sessions without video](#sessions-without-video)).

One **Data root** for all rigs (the field, or Browse…). Sessions land subject-first, exactly as
before: `<data root>/<mouse>/<mouse>_<date>/<session_id>/`. The rig that ran a session is in
its metadata and in the subject index (`<data root>/subjects/<mouse>.json`, written when the
session ends). If two rigs ever hold the same session id, the sync refuses that folder.

**Sync Now** — pick folders from the list (everything not green is pre-selected). For each folder
the controller takes a fresh inventory of it on the Pi, consolidates any session not yet folded
into one `.h5` (on the Pi, idempotent), and copies **whichever trees hold the folder** with
`rsync -rlt` over SSH (partial files are kept in `.rsync-partial` so a cancelled copy resumes).
It then re-inventories and runs the dry run again. Only if the folder's trees are unchanged, every
copy is clean and no recorded video is missing does it mark the folder green and record it in
`<data root>/.vrfarm_sync_ledger.json` (with `present: {data, video}`). Shepherd logs are mirrored
to `<data root>/shepherd_logs/<rig>/`.

**Sync & Poweroff** — first a dialog listing, per rig, what will be copied, which rigs are skipped
(running, unreachable, Deploy needed) and which folders can't be verified. On Yes: every folder
that is not green on every checked rig is synced, then for each rig where everything verified the
controller runs `sudo poweroff` on every follower and then on the leader and waits for port 22 to
close. A rig with a failed, missing or grey folder stays on. Do not cut power until a rig shows
**OFF**.

**Purge Data** — a dialog lists the folders that are green and fully consolidated, video-only
folders included. On confirm the controller takes a fresh inventory and re-runs the strict dry run
for every tree that holds each folder (plus a checksum pass if `verify_checksum_before_purge` is
on), then names exactly the copies that passed to the Pi (`--verified data:<folder>`,
`--verified video:<folder>`). The Pi-side script deletes only those. It refuses a whole folder if a
copy sits in a tree that was not verified or a verified copy has vanished, and refuses the whole
call if the engine is alive, a tree is unavailable, or no `--verified` was sent (an older
controller). It only accepts `<mouse>/<mouse>_YYYYMMDD` names inside the configured dirs.

**Auto purge** (toggle) — Sync Now and Sync & Poweroff purge each folder on the Pi right after its
verified copy, through the same re-verification as Purge Data. Stored in `controller.yaml`.

A job's progress (overall and per rig), its log and a Cancel button appear under the buttons.
One job runs at a time; inside a job the rigs run in parallel.

### Sessions without video

Leaving **Camera** unchecked at GO means no video folder is created for that session, so a date
folder may exist only in the data tree. The Data tab copies and purges tree by tree, so such a
folder syncs green and purges normally; a video folder whose data copy is already gone works the
same way.

To tell "not recorded" from "lost", GO sends the leader `camera_requested` (Camera checked) and
`camera_saved` (the camera Pi confirmed recording started) in the START message. The engine writes
them to `metadata.yaml`, and consolidation carries them into the `.h5` root attrs. A session with
`camera_saved: true` and no video on the leader is **missing**. Sessions recorded before this carry
neither flag and count as unknown, never as missing. A camera that was checked but never started
recording counts as not saved (GO already warned), and the sync log notes it.

If `video_dir` is on its own drive, name its mountpoint in the rig YAML:

```yaml
data:
  video_dir: /media/vruser/ssd/video
  video_mount: /media/vruser/ssd
```

While that path is not a mountpoint the video tree is **unavailable**: every folder of the rig is
grey, syncs fail after copying the data, consolidation waits, and nothing is purged. Without
`video_mount`, an unmounted drive would look like an empty video folder. cheddar keeps its video on
the boot NVMe (`/home/vruser/video`) and needs no `video_mount`.

The leader side is `shared/leader_data.py` protocol 2, which ships with **Deploy**. Until a rig is
deployed, its card says **Deploy needed** and sync and purge are refused.

## What runs where

| Piece | Where | Installed by |
|---|---|---|
| `rsync` >= 3.1 | controller | `conda install -n vrfarm -c conda-forge rsync` — `rsync_path: null` looks only in the env. On Linux, `rsync_path: /usr/bin/rsync` in `controller/configs/controller.yaml` works too (fystyk's env has no rsync, so it needs one of the two). On macOS `/usr/bin/rsync` is Apple's openrsync and is rejected with a banner in the Data tab. |
| `rsync` | every Pi | the Install step's apt list |
| `shared/leader_data.py` | leader Pis | rides Deploy and Install (`shared/deploy_manifest.py`) |

A rig installed before this change needs a **Deploy** (ships `leader_data.py`) and either a
re-**Install** or `sudo apt install rsync` on the leader. The Data tab says which is missing.

## Settings: `controller/configs/controller.yaml`

Machine-specific, gitignored, created on first run from `controller_template.yaml` in the same
folder: UI port, the controller's IP (for the diagram), the event port, data root, auto purge, the
rsync path, sync tuning (`parallel_rigs`, `bwlimit_mbps`, `verify_checksum_before_purge`,
`shepherd_logs_keep_days`) and the rig groups. Per-rig settings stay in `rigs/<rig>.yaml`.
`VRFARM_SETTINGS=<path>` points the app at another file (the tests use a scratch one).

The file used to sit at the repo root. A `controller.yaml` still there is moved into
`controller/configs/` the next time the controller starts; if one already exists there, that one
wins and the old file is ignored (the log says so).

## Calibration files per rig

Each rig has `display_calibration/<rig>/geometry/` (dated geometry files), `intensity/`
(intensity calibrations: measured `intensity_cal_*` plus theoretical and none mocks) and its `warp_map.npz`; see
[display_calibration/README.md](../display_calibration/README.md#where-the-files-live). The
folders are created the first time the Setup tab touches a rig; a rig without geometry is seeded
from `display_calibration/_template/geometry/rig_geometry_template.yaml`.

The geometry tool on the display Pi reports a saved geometry back to
`/api/rigs/<rig>/setup/receive_geometry`; the Setup tab passes that address to `cal_start.sh`
as `CAL_MAC_URL`.

## Adding a rig

1. Network → **Add rig**: name it, accept the suggested IP pair, keep the default devices.
2. Set the two Pis' static IPs to match, put them on two free RJ45 ports of the switch. Not while
   another rig is mid-session: recabling the switch once stalled a live Pi port for minutes.
3. Setup → Load rig → Pi cards → **Install** on each Pi (first time), then **Deploy**.
4. Setup → **Initialize** and calibrate the display as usual.
5. Network → add the rig to a group if you run it with others.

## Testing without hardware

```bash
python tools/smoke_multirig.py     # two fake rigs (mock Pis) through connect/deploy/go/end/reset
python tools/smoke_data.py         # the Data tab against a scratch data tree on this machine
python tools/capture_ui_shots.py   # Playwright walkthrough of all four tabs -> docs/images/
```

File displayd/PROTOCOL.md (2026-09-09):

# displayd — interfaces and contracts (phase 2)

The display daemon for the KMS display Pi. Two processes: `displayd.py` (control,
health, DLPC, supervision — system python3, stdlib+PyYAML only) and its child
`renderer.py` (sole DRM master — system python3 + python3-pygame/numpy). Design
rationale and failure playbook: the displayd design spec (bench 2026-08-22/23).
Everything here targets the follower's SYSTEM python (3.13 on trixie) — the conda
env's SDL has no kmsdrm and must never run either process.

## Files

- `displayd/displayd.py`   — daemon entry: `python3 displayd.py --rig <yaml>`
- `displayd/renderer.py`   — child entry (spawned by displayd only): inherits fd 3 =
  its end of an AF_UNIX SOCK_DGRAM socketpair
- `displayd/dlpc.py`       — DLPC3436 I2C wrapper (imports the vendored SDK from
  `~/dlp`; sys.path append `~/dlp` + `~/dlp/api`)
- `displayd/displayd.service` — systemd unit, installed to /etc/systemd/system,
  shipped DISABLED (phase 3 enables)
- Deployed under `~/rig/displayd/`; `devices/display.py` (already in `~/rig`) is
  imported by renderer.py for drawing (sys.path insert `~/rig`).

## Ports (network block of the rig yaml; defaults in code)

- `display_port` 5575/udp — leader engine session channel (bind 0.0.0.0)
- `ack_port` 5573/udp — displayd -> leader (ACK/ONSET/display_health); leader binds
- `displayd_ctl_port` 5581/tcp — control REST, 127.0.0.1 ONLY
- `displayd_pd_port` 5582/udp — leader photodiode -> displayd pulse ingest (phase 2:
  bind + buffer; the correlator consumes it in phase 3)

## Lifecycle state machine (states exactly as reported in /status)

BOOT -> CONFIG_OK -> DLPC_ALIVE -> VIDEO_UP -> DLPC_LOCKED -> CURTAIN_DOWN
     -> RENDERER_UP -> OPTICS_OK ; FAULT(reason) from any transition failure.
Repair states: REINIT_DLPC (auto on L1 source-revert), MODESET_KICK, RENDERER_RESTART.

- CONFIG_OK: /sys/class/drm/card*-DPI-1/status == "connected" and modes contain
  1920x1080. (No config.txt hash check — a plain presence check; the critique's note.)
- DLPC_ALIVE: one ShortStatus read succeeds. Reported as "logic powered", NEVER
  "projector on" (back-feed).
- VIDEO_UP: `pinctrl set 25 op dh` (idempotent).
- DLPC_LOCKED: run the init sequence (dlpc.init_parallel()), readback SourceSelect ==
  external parallel, then sleep 2.5 s (light settle).
- CURTAIN_DOWN: curtain readback == off.
- RENDERER_UP: renderer child spawned; its startup contract passed (see below);
  first flip report received.
- OPTICS_OK: phase 2 = parked with `optics: "unverified"` unless a manual
  /render sync_burst + external confirmation is recorded; the L3 correlator
  arrives in phase 3. The state machine must expose this honestly in /status.
- MODESET_KICK: stop renderer -> `timeout 2 modetest -M vc4 -s DPI-1:1920x1080`
  -> respawn renderer. NEVER unbind vc4_dpi (kernel oops).

## Renderer startup contract (hard-fail; each clause is a bench-caught bug)

1. `SDL_HINT_NO_SIGNAL_HANDLERS=1`, `SDL_VIDEODRIVER=kmsdrm`, no DISPLAY.
2. `pygame.display.set_mode((1920,1080), FULLSCREEN|SCALED, vsync=1)`.
3. Assert `pygame.display.get_driver() == "KMSDRM"` (null-backend fallback is silent).
4. 30-frame self-test: measured fps within 57.46±1.5 AND mean flip-block >= 8 ms.
5. On any failure: send `{"ev":"fatal","reason":"NULL_BACKEND|FPS_OUT_OF_RANGE|
   SDL_ERROR","detail":...}` up the socketpair and exit(3). displayd surfaces the
   reason verbatim and does not blind-retry more than once.

## displayd <-> renderer socketpair (JSON per datagram, fd 3 in the child)

Every down-op carries a monotonic "id"; results echo it (displayd correlates by
id, falling back to action name for older renderers).
down: {"op":"mode","lease":"idle"|"setup"|"session","config":{...display device
       config: rig devices.display merged with the photodiode sync_* keys, exactly
       engine/follower.py's merge — arrives on EVERY mode op, apply idempotently}}
      {"op":"load_stims","path":"/home/vruser/rig/stims/<sid>/stimuli.npz"}
      {"op":"show","seq":42,"trial":7}
      {"op":"render","action":"blank"|"checkers"|"stimulus"|"reload_warp"|
       "sync_test"|"stop_sync"|"sync_burst", ...params identical to the old
       display_worker actions...}   # session BG/BLANK add "use_session_bg":true
       # -> the device's plain blank() (NPZ background gray), never black
      {"op":"heartbeat_flash"}          # one red sync-square frame, then restore
      {"op":"quit"}
up:   {"ev":"ready","driver":"KMSDRM","fps":57.46,"flip_ms":13.5}   # after self-test
      {"ev":"flip","t":<wall>,"flip_ms":13.5,"n":<flips represented>}  # sampled
      # every 0.25 s (the old 1/60 s throttle never fired against a 17.4 ms frame)
      {"ev":"onset","seq":42,"trial":7,"t":<wall>,"flip_ms":13.5}
      {"ev":"flash","t_cmd":<wall>}                  # heartbeat flash flip time
      {"ev":"result","op":"sync_burst","id":<echo>,"flashes":12,"flash_times":[...]}
      {"ev":"fatal","reason":...,"detail":...}
      {"ev":"log","line":"..."}

## Session channel (UDP :5575) — leader engine compatible

Phase 2 keeps follower.py's message names so the existing leader works unchanged:
SHOW {trial}, BG, BLANK, LOAD_STIMS {path}, SYNC_TEST {...}, QUIT (ignored with a
log — the daemon never exits), plus new: PING -> PONG {state}. Replies/acks go to
`ack_port`: on SHOW's first flip send {"type":"stim_onset","trial":N,"t":...} —
the same shape follower.py sends today. Seq-numbered SESSION_BEGIN arrives with
the phase-3 leader; tolerate unknown cmds with a log line.

## Control REST (:5581, localhost; stdlib ThreadingHTTPServer)

GET  /status  -> {"state":..., "since":..., "optics":"unverified"|"ok",
                  "dlpc":{...latest sweep, latched:{bit: since_t} (fault bits only,
                    retained 300 s from last assertion), read_errors:{name:msg}...},
                  "renderer":{"pid":..., "fps":..., "flip_ms_p99":..., "restarts":N},
                  "lease":{"mode":"idle|setup|session|external","holder":...},
                  "alarms":[...last 20...]}
POST /bringup -> walk CONFIG_OK..RENDERER_UP; body {} ; returns /status shape
POST /lease   -> {"mode":"setup"|"external"} ; POST /release
POST /render  -> forward body to renderer {"op":"render",...}; returns its result
POST /recover -> {"action":"modeset_kick"|"dlpc_reinit"|"renderer_restart"}
GET  /health/history?n=100 -> alarm/event ring

## L1 poller (thread in displayd)

1 Hz sweep via dlpc.sweep() (the bench 18-read set, ~8.6 ms). Continuous from
daemon start; keeps {live_snapshot, latched_since{bit:t}} — first read after an
event is history (latch semantics). Detections -> alarms + auto-transitions:
SourceSelect != parallel -> REINIT_DLPC; ActuatorWatchdogTimerTimeout==1 ->
alarm "input signal lost". NAK -> alarm "DLPC unreachable" (logic power lost —
rare; back-feed). All alarms: append to ring + send {"type":"display_health",...}
to leader ack_port + print one journald line.

## dlpc.py API

class Dlpc: open()/close(); sweep() -> {"ok":bool, "reads":{name:{...}},
"errors":{name:msg}} (defensive: NameError == no-response; never trust
Summary.Successful on writes); init_parallel() (the init_parallel_mode.py
command sequence in-process, curtain try/finally); read_source() / read_curtain()
/ read_short() convenience. A single threading.Lock serializes ALL bus access.

## displayd.service

[Unit] Description=VRFarm display daemon; After=network-online.target
[Service] User=vruser; ExecStart=/usr/bin/python3 /home/vruser/rig/displayd/displayd.py --rig /home/vruser/rig/rigs/<name>.yaml
Restart=always; RestartSec=2; WatchdogSec=15; Type=notify (sd_notify via a ~10-line
AF_UNIX datagram helper — no python3-systemd dep). Journald gets stdout/stderr.
Shipped disabled: Install writes the unit + `systemctl daemon-reload`, no enable.

## Install additions (controller/setup.py, follower role)

- apt: python3-pygame python3-numpy python3-yaml libdrm-tests (+ apt-mark hold
  libsdl2-2.0-0 python3-pygame)
- write /etc/systemd/system/displayd.service (scp + sudo mv), daemon-reload
- KMS config: copy dlp/sample_config/config_kms.txt to /boot/firmware/ as
  config_kms_candidate.txt ONLY (never activate config.txt in phase 2)
- deploy manifest: displayd/*.py join the follower list

## Non-goals in phase 2 (phase 3+)

Leader-side HB_FLASH scheduler + correlator; seq-numbered SESSION_BEGIN protocol;
pi_api forwarding of the old endpoint names to :5581; /api/start translation shim;
deletion of follower.py/display_worker.py; enabling the service.

# ── Phase 3 additions ──────────────────────────────────────────────────────────

## Daemon-mode detection (pi_api)

pi_api decides daemon vs legacy per request by probing GET 127.0.0.1:5581/status
(timeout 0.5 s). Alive -> daemon mode. No config flag, no state: enabling/stopping
displayd.service IS the switch, and old controllers keep working through the shim.

## pi_api forwarding (daemon mode)

- /api/init_projector      -> POST :5581/bringup (never start_projector.sh/X)
- /api/init_display        -> GET :5581/status (renderer is always up; returns ok
                              when state==RENDERER_UP, plus the status blob)
- /api/shutdown_display    -> POST :5581/release (lease release; daemon never exits)
- /api/blank_display, /api/test_checkers, /api/test_stimulus, /api/reload_warp,
  /api/photodiode_test_start|stop, /api/photodiode_sync_burst
                           -> POST :5581/render with the mapped action + params
                              (identical param names; sync burst returns flashes
                              + flash_times)
- /api/start {script:"follower", args:[..., "--stims", PATH]}  (the SHIM)
                           -> do NOT spawn a process. Send LOAD_STIMS {path:PATH}
                              to 127.0.0.1:5575, return {ok, daemon:true}. The
                              leader's SYNC_TEST retry loop remains the readiness
                              barrier. /api/stop with the daemon alive sends
                              nothing (QUIT is ignored anyway) and reports ok.
- /api/restart             -> 409 {"error":"session lease active"} when :5581
                              /status.lease.mode == "session" (unless force:true).
Legacy paths stay intact when the daemon is down (phase 4 deletes them).

## Leader-clocked L3 heartbeats (engine/leader.py)

- Scheduler: when the photodiode device exists AND task stimulus.photodiode_sync_enabled
  is true, every hb_period_s (default 5.0, task/device override "heartbeat_period_s")
  while NO stim window is active: record t_cmd = time.time(), send
  {"cmd":"HB_FLASH","seq":k} to every follower :5575. displayd forwards
  heartbeat_flash to the renderer and reports {"type":"hb_flash","seq":k,"t_flip":...}
  back on ack_port; the leader stores t_flip (fallback t_cmd + 0.05 if no report).
- When photodiode_sync_enabled is FALSE: no heartbeats, and one
  {"type":"display_health","alarm":{"kind":"optics_watch_off",...}} event is
  published at session start — the named degraded mode, never silence.
- Correlator (leader-side, single clock): photodiode pulse times arrive from the
  existing GPIO callback (already leader-clock). Cluster pulses: gap > 30 ms starts
  a new cluster (one flash = 2-3 sub-pulses at 8.7 ms). A heartbeat is CONFIRMED if
  a cluster onset lands in [t_flip - 0.020, t_flip + 0.070]. 3 consecutive
  unconfirmed heartbeats -> publish {"type":"display_health","alarm":{"kind":
  "heartbeat_lost",...}} + Slack notify (via the controller's existing event->
  notify path); recovery event after 2 consecutive confirmed. Stim windows: the
  existing per-trial sync path (sync_queue first-pulse) is unchanged and doubles
  as the in-stim heartbeat; the scheduler pauses from SHOW until stim_off.
- Verdict feedback (pd port :5582, leader -> displayd): every judged heartbeat is
  reported as {"type":"hb_verdict","seq":k,"confirmed":bool,"t":...}. The daemon owns
  the display but cannot see its own light, so this is the ONLY way it learns whether
  its output reaches the diode. displayd streaks these with the same thresholds the
  leader uses (2 confirmed -> optics "ok", 3 unconfirmed -> optics "lost") and resets
  to "unverified" whenever the renderer respawns, since a new process's optics are
  unproven. Fire-and-forget: the leader's own alarm is the authority. Reported in
  /status.optics ONLY — ST_OPTICS_OK remains unentered until phase 4 revisits the
  state ladder, so this does not alter bringup or recovery control flow.
- Display-fault abort (engine/leader.py, session.abort_on_display_fault, default
  true; needs photodiode sync): evaluated at the END of a trial, never mid-cue.
  Aborts when abort_after_bad_trials (default 3) consecutive stimuli record
  sync_ok == 0, or when the heartbeat alarm stands AND this trial's stimulus was
  unconfirmed. A standing alarm alone is deliberately insufficient — a confirmed
  stimulus proves light is arriving now. Publishes {"type":"display_abort","trial",
  "cause","reason","n_bad"} (controller pages Slack immediately), sets metadata
  end_reason: "display_fault" plus an "abort" block, and session_end carries
  end_reason so an aborted run never reports as a clean finish.
- Loss localization: heartbeat_lost carries "cause" from the Teensy's 1 Hz
  "B <floor> <ceil>" idle line, which reports the analog front end independently of
  pulse detection — no_telemetry / sensor_dead (B absent >3 s) / ttl_dead (light seen,
  no TTL edge) / no_light (front end alive, genuinely dark). no_light does NOT claim
  the projector failed: a covered or misaimed diode is equally dark from here, and
  only L4 can separate those.
- Per-trial record: sync_ok becomes tri-state int: 1 confirmed, 0 failed (sync
  enabled, no pulse), -1 unavailable (sync disabled). New per-trial field
  onset_source: "photodiode" | "ack" | "command" — the best available onset
  anchor (photodiode pulse > displayd stim_onset ack > SHOW send time); the
  chosen onset keeps feeding true_onset_t exactly as today.

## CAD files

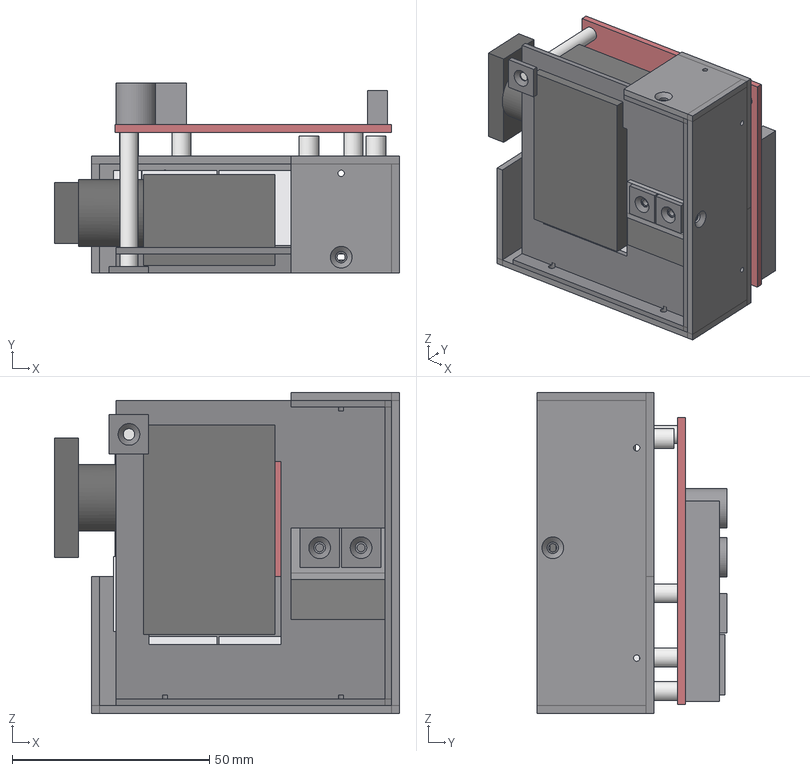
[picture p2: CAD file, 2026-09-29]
display_diagnostics/projector_model/dlpdlcr230npevm_simplified.step
87.4 x 48.2 x 81.4 mm
MCH051_base
MCH053_formatter_base
MCH052_fan_bracket
fan_25mm
DLP038_pcb
pcb_components
standoffs
FLA12F_engine
lens
led_heatsinks

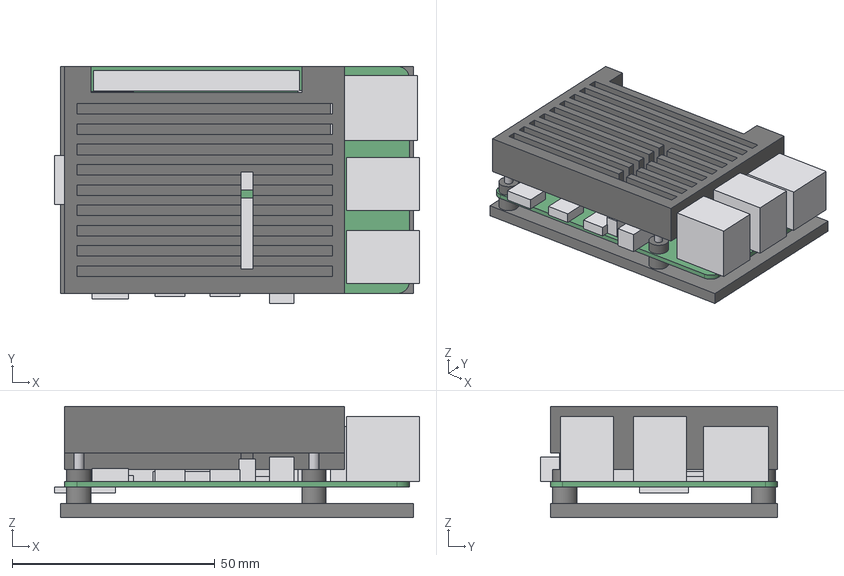
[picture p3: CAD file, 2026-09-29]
display_diagnostics/rpi4_model/rpi4b_joyit_armor_case_simplified.step
90.0 x 58.5 x 27.4 mm
rpi4b_pcb
rpi4b_connectors
joyit_top_block
joyit_bottom_plate
screws_M2.5

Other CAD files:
display_diagnostics/projector_model/dlpdlcr230npevm_simplified.stl
display_diagnostics/rpi4_model/rpi4b_joyit_armor_case_simplified.stl

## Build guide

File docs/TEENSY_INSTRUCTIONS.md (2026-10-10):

# Teensy Firmware — Photodiode Sync Detector

**Board:** Teensy 4.0 (`teensy:avr:teensy40`), USB-attached to the **leader Pi** of its rig, where it
is also flashed (Setup UI → photodiode card → **Teensy firmware → Upload**)
**Last updated:** 2026-10-07
**Files:** [`teensy/photodiode_sync_v2_2/`](../teensy/photodiode_sync_v2_2/) (current) · earlier
versions alongside · [`teensy/00-teensy.rules`](../teensy/00-teensy.rules) (PJRC udev rules Install puts on the Pi) ·
[`teensy/teensy_hid_reboot.py`](../teensy/teensy_hid_reboot.py) (reboots a fresh RawHID board into its bootloader)
**Related:** [LEADER_WIRING.md](LEADER_WIRING.md) (where `OUT_PIN` lands on the Pi header) ·
[CALIBRATION_PROTOCOL.md](CALIBRATION_PROTOCOL.md)

---

## What it does

The Teensy reads the photodiode voltage on an analog pin, thresholds it with the same two
filters as the setup UI (steady/glitch + hold-off), and emits a clean **3.3 V square pulse**
on `OUT_PIN` to the RPi GPIO for every detected sync pulse. This solves the "photodiode ~2 V
< Pi logic-high" problem — the Teensy's 3.3 V logic drives the Pi input directly.

`v2_0` adds **adaptive thresholds**: the Schmitt thresholds ride a live baseline/peak
estimate instead of being fixed voltages, so they self-adjust as the diode's idle level
drifts. Set `ADAPTIVE 0` in the sketch to fall back to the `v1_0`-style fixed thresholds.

| Pin | Role |
|---|---|
| `A1` (`PD_PIN`) | photodiode analog input — **must be ≤ 3.3 V at the pin** |
| `16` (`OUT_PIN`) | square-pulse output → RPi GPIO16 (idles LOW, pulses HIGH) — scope-verified on the rig 2026-08-23; older docs said pin 1 |

> ⚠️ **Teensy 4 analog pins are 3.3 V max and NOT 5 V-tolerant.** The photodiode swings
> above 5 V, so a divider or Schottky clamp is mandatory ahead of `PD_PIN`. Set `DIVIDER`
> in the sketch to your divider ratio so the debug output prints true photodiode volts.

---

## Flashing from the Setup UI (the normal way)

The sketch is compiled and flashed **on the leader Pi that owns the photodiode device** — the Teensy
hangs off that Pi's USB, one Teensy per rig. In the Setup tab, photodiode card, **Teensy firmware**
row: **Browse** picks a local `.ino`; with no file chosen the server flashes the newest sketch under
`teensy/<rig>/` when that rig has its own copies, else the newest shared `teensy/` sketch. **Debug**
patches `#define DEBUG`, **Upload** does the rest and logs each step. Nothing on the controller is
needed.

**Per-rig copies.** Pins and thresholds differ between rigs, so a rig can carry its own copy of the
current sketch in `teensy/<rig>/<sketch>/<sketch>.ino` (cheddar: stock A1 / pin 16 / `MIN_PULSE_V`
0.30; morbier: A0 / pin 3 / 0.15, measured 2026-10-10: flashes 0.34 V above a 0.04 V floor, the
projector's black-level red segments 0.07 V). When a new sketch version lands in `teensy/`, copy it
into each rig folder and re-apply that rig's three lines.

**Toolchain on the Pi.** Install puts it on the Pi that has the photodiode (step 4b), and Upload
installs whatever is missing before compiling, so a leader that was installed earlier needs no
re-Install. The Pi downloads these itself over the institute WiFi:

| Part | Where | What for |
|---|---|---|
| `teensy-loader-cli` (apt) | `/usr/bin` | flashes the `.hex` over USB (HalfKay bootloader) |
| `arduino-cli` (ARM64 build) | `~/bin/arduino-cli` | compiles the sketch |
| Teensy core `teensy:avr` (PJRC board index) | `~/.arduino15` (~650 MB) | board support + compiler |
| PJRC udev rules | `/etc/udev/rules.d/00-teensy.rules` | Teensy USB and `ttyACM*` nodes mode `0666`, `stty raw -echo` at plug-in, ModemManager kept off the port |

**First flash of a fresh Teensy.** A new board enumerates as `16c0:0486 Teensyduino RawHID` with no
`/dev/ttyACM0`. The loader's own soft reboot only speaks to the Serial USB identity, so Upload first
sends the Teensyduino reboot request over HID ([`teensy/teensy_hid_reboot.py`](../teensy/teensy_hid_reboot.py),
the same 4-byte feature report the Teensy Loader GUI uses); the board drops into its HalfKay
bootloader and is programmed with no button press. Only if that fails does the log ask you to
press the button (the loader then waits about two minutes). Once our sketch runs the board is
`16c0:0483 Teensyduino Serial` with `/dev/ttyACM0`, and every later Upload soft-reboots it.

## Manual build on the Pi (fallback)

```bash
ssh vruser@<leader>
~/bin/arduino-cli compile --fqbn teensy:avr:teensy40 --output-dir ~/teensy_build/out ~/teensy_build/photodiode_sync_v2_2
teensy_loader_cli --mcu=TEENSY40 -s -w -v ~/teensy_build/out/photodiode_sync_v2_2.ino.hex
```

Upload leaves the sketch in `~/teensy_build/<sketch>/` on the Pi, so the paths above exist after
one Upload. `-s` soft-reboots a Serial-mode board, `-w` waits for the bootloader (button) otherwise.
`arduino-cli board list` shows the Teensy as a `teensy`-protocol port (e.g. `usb1/1-1`); the
`/dev/ttyACM0` line is the serial endpoint, not an upload target.

Reference build for `v2_0` on a Teensy 4.0:

```
FLASH: code:9252, data:3016, headers:8208   free for files:2011140
 RAM1: variables:3520, code:7536, padding:25232   free for local variables:488000
 RAM2: variables:12416  free for malloc/new:511872
```

---

## Debug / tuning mode

Production builds are **silent on serial** — `#define DEBUG 0` in the sketch. Seeing no
serial output after a flash is expected, not a fault.

Set `DEBUG 1` and reflash to stream four space-separated traces at 115200 baud for the
Arduino Serial Plotter (the onboard LED also mirrors the output):

| Trace | Signal |
|---|---|
| 1 | raw photodiode volts |
| 2 | live START threshold (crossed up to begin a pulse) |
| 3 | live END threshold (crossed back down to end it) |
| 4 | detection marker — full-scale while a pulse is accepted |

Read it from the command line with:

```bash
stty -F /dev/ttyACM0 115200    # udev already applied `raw -echo` at plug-in
cat /dev/ttyACM0
```

Tuning, while running the setup-UI photodiode **Test**:

- Flash never reaches trace 2 → lower `START_FRAC` (adaptive) or `THRESHOLD_HI_V` (fixed).
- Traces 2/3 hug the noise and trace 4 flickers while idle → raise `MIN_PULSE_V`.
- Thresholds sag when flashes pause, then snap back → that's the `MIN_PULSE_V` floor
  working; raise it only if the sag dips too low.

**Set `DEBUG` back to 0 and reflash before running an experiment.**

---

## Troubleshooting

| Symptom | Fix |
|---|---|
| Upload log: `arduino-cli: No such file` or `teensy_loader_cli: not found` | The toolchain install failed (no internet on the Pi?) — Upload retries it; check the Pi's WiFi |
| Loader waits, nothing happens | The HID reboot did not take (log says so): press the Teensy's button once; or the udev rules are missing — Upload installs them, then replug the Teensy |
| `Unable to open /dev/ttyACM0 for reboot request` | pi_api's photodiode holds the port — the loader falls back to waiting for the button; press it |
| No serial output | Expected in production — `DEBUG` is 0 |
| Pi sees no sync pulses | Check `OUT_PIN` wiring and that `DEBUG` builds are not still loaded |

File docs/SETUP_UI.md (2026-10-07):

# Setup UI — building and maintaining a rig

**Last updated:** 2026-08-17

The setup UI is where a rig is *defined and serviced*: which Pis exist, which devices
hang off them, what pins and calibrations they use, and how code gets onto the hardware.
You use it when building a rig, after changing wiring, after editing code, and for
projector calibration. You do **not** use it to run a session — that is the
[Experiment tab](EXPERIMENT_UI.md). Since the multi-rig controller, Pi names / IPs / roles are
edited in the **Network** tab, rigs are created and deleted there too, and Setup shows one sub-tab
per loaded rig ([MULTI_RIG.md](MULTI_RIG.md)).

```bash
conda activate vrfarm
python controller/app.py     # http://localhost:5000 -> Setup tab
```

It writes `rigs/<name>.yaml` and `display_calibration/<rig>/geometry/rig_geometry_<stamp>.yaml` (plus intensity files in `display_calibration/<rig>/intensity/`), and together
with the Data tab it is the part of VRFarm that uses SSH — Install, Reboot, Shutdown, warp generation and
geometry calibration all shell out over `ssh`/`scp`. See
[CONTROLLER_SETUP.md §2](CONTROLLER_SETUP.md#2-passwordless-ssh-to-the-pis) if those
fail with a password prompt.

> Every screenshot below is the hardware-free `demo` rig (both Pis on `127.0.0.1`,
> answered by `tools/mock_pi.py`). Regenerate them all with
> `python tools/capture_ui_shots.py`.

---

## The page at a glance

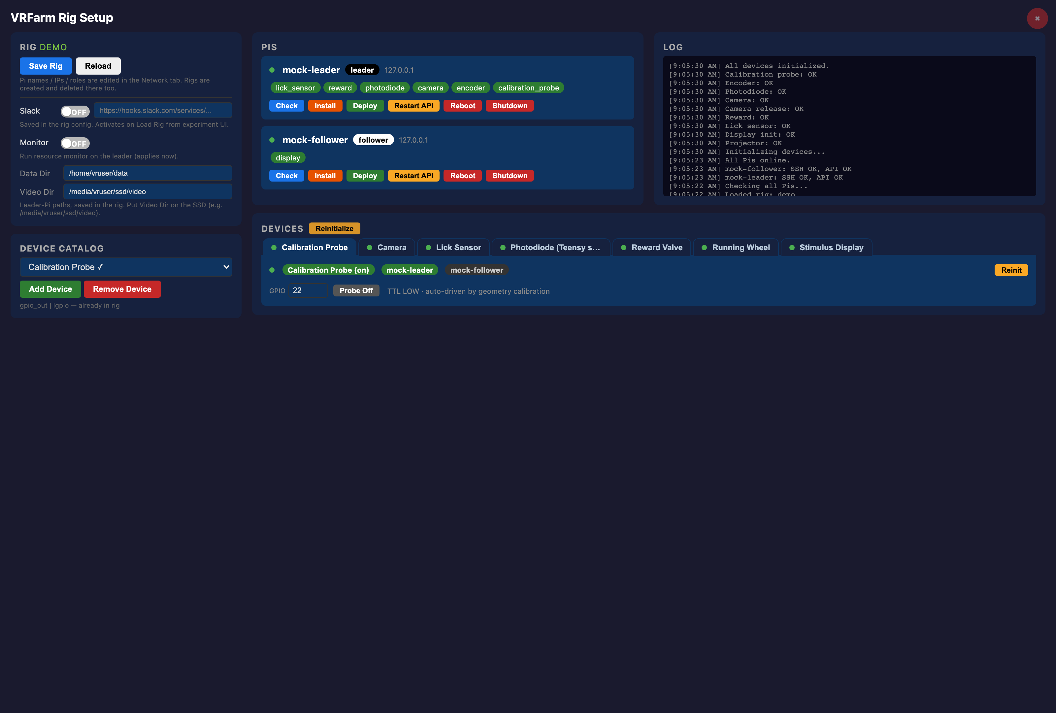
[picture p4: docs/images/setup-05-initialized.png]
Setup UI with a rig loaded and every device initialized


Three columns, and the layout maps onto the workflow:

| Region | Card | What it is for |
|---|---|---|
| Left | **Rig** | Load / create / save a rig file; Slack; the Leader's data + video paths |
| Left | **Pi Management** | Add, edit and remove Pis in the loaded rig |
| Left | **Device Catalog** | Add or remove device *types* from the rig |
| Middle | **Pis** | One card per Pi: status dot, assigned devices, and the six service actions |
| Middle | **Devices** | A tab per device with its live controls — the working area |
| Right | **Log** | Reverse-chronological; every action reports here. Read it when something fails |

The red **×** at top right stops the Flask server.

---

## Order of operations

The UI enforces a strict sequence through button enablement. Fighting it is the most
common source of "why is everything greyed out".

```
Load Rig ──> Check (per Pi, automatic) ──> Initialize ──> device controls unlock
   │                                           ▲
   └─ Install (fresh Pi, once) ── Deploy ──────┘   (both revert devices to uninitialized)
```

1. **Nothing works before a rig is loaded.** Add Pi, Add Device and the update controls
   all bail with *"Load or create a rig first"*. On a cold start the Pis and Devices areas
   are empty and **Initialize** is greyed:

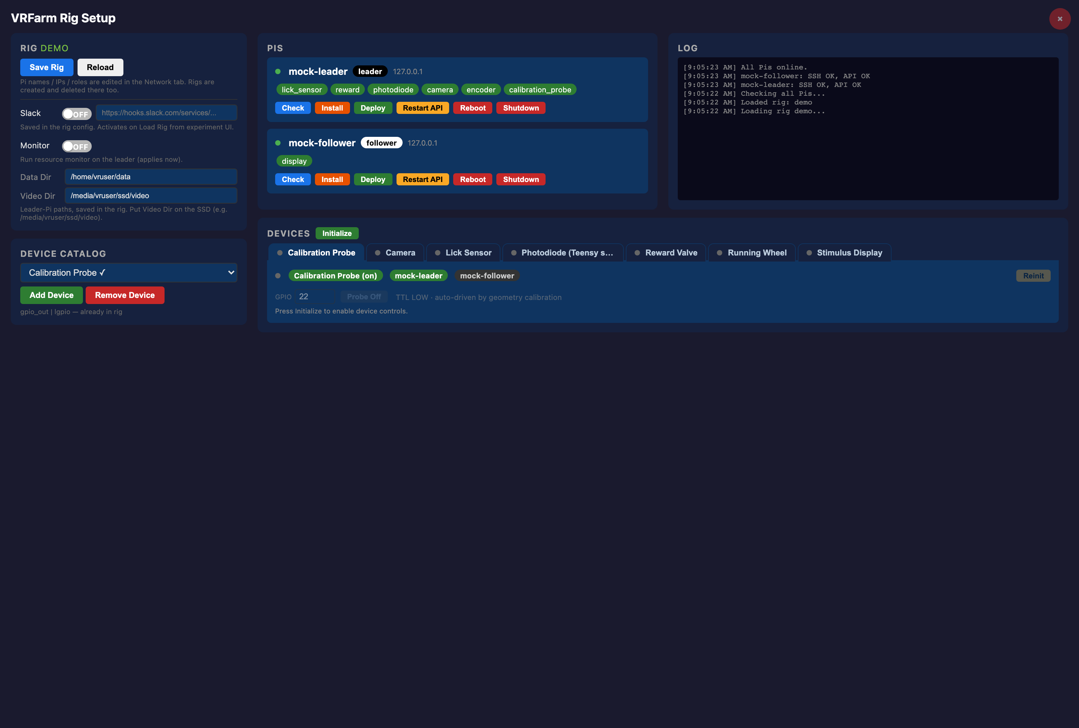
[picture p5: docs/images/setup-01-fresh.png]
Setup UI on first load, no rig selected
   
2. **Load Rig auto-checks every Pi.** There is no Connect button; per-Pi **Check** is the
   manual re-run.
3. **Initialize is the master gate.** It stays disabled until *every* Pi answers on its
   REST API. Until it succeeds, every device panel is greyed with *"Waiting for Pi
   check..."* or *"Press Initialize to enable device controls."*
4. **Deploy and Restart API un-initialize everything.** Both restart `pi_api` on the Pi,
   which drops the device handles — the dots go grey and you press **Initialize** again.
   This is expected, not a failure.

Straight after Load Rig the Pis are green and **Initialize** has gone live, but the device
area is still empty — that is the moment to press it:

Rig loaded, Pis green, devices not yet initialized

---

## Rig card

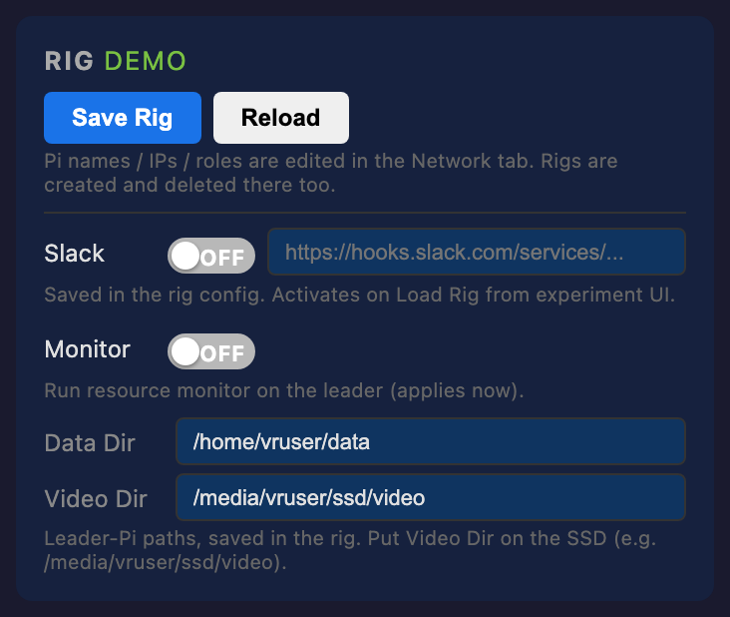
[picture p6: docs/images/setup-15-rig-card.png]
Rig card


| Control | Effect |
|---|---|
| **Load Rig** | Reads `rigs/<name>.yaml`, then automatically checks the warp map and every Pi |
| **New Rig** | Prompts for a name and **immediately writes** `rigs/<name>.yaml` — a same-named rig is overwritten without warning |
| **Save Rig** | Writes the rig YAML **and** the currently loaded geometry file in one click |
| Slack + webhook | Stored in the rig; the *experiment* UI activates it on its own Load Rig |
| **Monitor** toggle | Starts/stops [shepherd](../shepherd/README.md), the health watchdog on the Leader. Applies immediately, and is re-applied on Install |
| Data Dir / Video Dir | **Leader-side** paths. Point Video Dir at the SSD — the Leader's card cannot hold video |

`Save Rig` is the single persistence point. Pi edits, device assignments, pin numbers,
calibration tables and geometry parameters all live in memory until you press it.

---

## Pi Management

Add a Pi with **Name / IP / User / Role**; `role` must be `leader` or `follower`. To edit
one, pick it under *Target Pi*, choose the field, type the new value, **Update Pi**. Name
and IP collisions are rejected, and changing an IP migrates that Pi's status internally.

All three buttons are client-side only — **Save Rig** persists them.

## Device Catalog

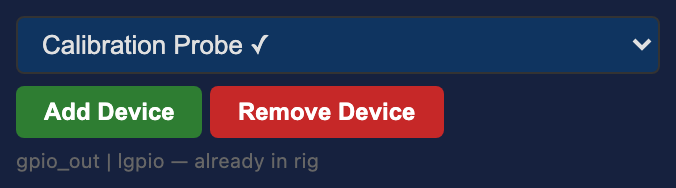
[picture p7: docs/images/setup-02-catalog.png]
Device catalog


The dropdown lists every registered device class, with `✓` on those already in the rig.
The grey line underneath shows its I/O type and required packages (e.g.
`gpio_out | lgpio`) — that is what **Install** will put on the Pi.

Adding a device puts it in the rig but **not on a Pi**. You must then open its tab and
click the Pi-name chip to assign it. An unassigned device can never initialize.

---

## Per-Pi actions

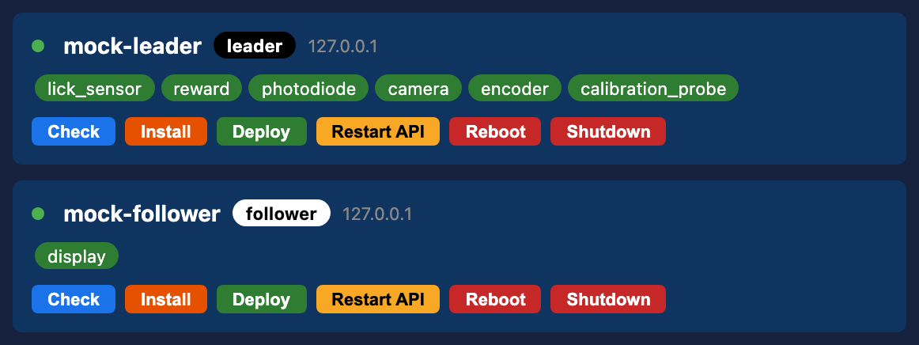
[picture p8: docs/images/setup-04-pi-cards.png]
Pi cards


The dot is **green** when both SSH and the Pi's REST API answer, **yellow** when SSH works but pi_api
does not (Install or Restart API fixes that), **red** when SSH fails, grey until checked. The chips are
its assigned devices.

| Button | What it does | When to use it | Risk |
|---|---|---|---|
| **Check** | SSH `echo ok` + `GET /api/status` | Any time; ~5 s | none |
| **Install** | Full first-time provisioning: conda `rig` env pinned to the system Python, apt packages, I²C enable, binding symlinks, pip, the Teensy toolchain on the photodiode Pi, all code, `config.txt`/`xorg.conf`, systemd units, time zone `Europe/Vienna` | **Once**, on a fresh Pi | **Minutes; rewrites boot config.** Needs passwordless sudo. Reboot the follower afterwards |
| **Deploy** | Uploads current code, restarts shepherd (leader) and `pi_api`. The restart is timed: the leader's shepherd then waits that long ×1.5 (5–60 s) before reporting pi_api down | After **every** code change | Drops initialized devices |
| **Restart API** | Asks `pi_api` to self-kill; systemd respawns it. Timed like Deploy | When the API is wedged | Drops initialized devices |
| **Reboot** | `sudo reboot` | After Install on the follower | Pi offline ~40 s |
| **Shutdown** | `sudo shutdown -h now` | End of life | **Needs physical access to power back on** |

**Install** is disabled when SSH fails; the other five are disabled when the API is down.
A Pi showing *"SSH FAIL, API OK"* still works for everything except Install.

---

## Initialize

Press **Initialize** (in the Devices header) once all Pis are green. It initializes each
enabled device on its assigned Pi in a fixed order — display first, then lick sensor,
reward, camera, photodiode, encoder, calibration probe — and reports each in the Log.

Device tabs

Afterwards the button becomes yellow **Reinitialize**, each tab carries a status dot
(green = up, red = failed, grey = untried), and every panel's controls unlock. A device
that is switched off shows a dimmed label. Per-card **Reinit** re-runs a single device
without touching the others — the fastest way to recover one failed sensor.

---

## Device cards

Each card edits **rig-config** values — pins, addresses, calibration — not task
parameters. Task parameters live in `experiments/*.yaml` and are edited in the
experiment UI.

### Camera

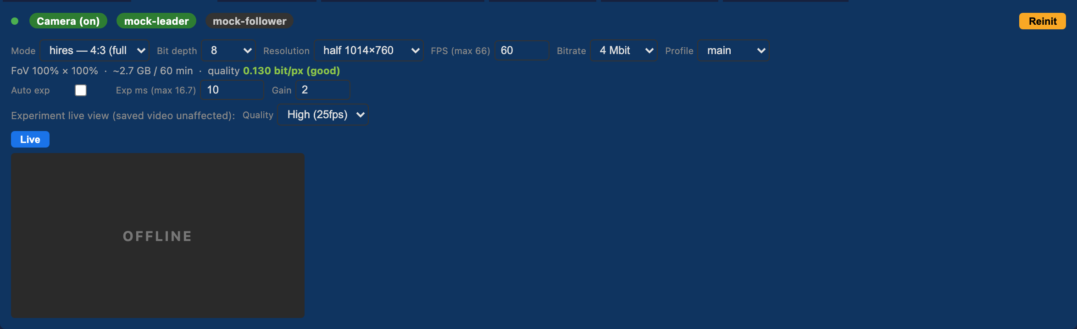
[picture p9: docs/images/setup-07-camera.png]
Camera card


Stream settings are locked while streaming — press **Stop** to change them. `Exp ms` is
clamped to `1000/fps`, and the frame rate is clamped to the sensor's ceiling so you cannot
over-request one and silently under-deliver.

| Control | What it sets |
|---|---|
| **Mode** | Sensor readout mode — the raw window the sensor scans (e.g. `2028×1520`). Determines the field of view and the achievable frame rate |
| **Resolution** | The encoded output size, downscaled from the sensor mode |
| **FPS** / **Bit depth** | Frame rate and sensor bit depth. Higher bit depth costs bandwidth and caps the frame rate |
| **Bitrate** / **Profile** | H.264 target bitrate and profile. The Pi 5 has no hardware encoder, so these directly drive CPU load — see [shepherd](../shepherd/README.md) |
| **Auto exp** / **Exp ms** / **Gain** | Exposure. Manual fields grey out under Auto |
| **Quality** (*Experiment live view*) | Preview only — never affects the recorded file |

The grey line under the controls is derived live from those settings — field of view
retained, projected file size per hour, and encode quality in bits/pixel. Use it to trade
resolution against disk before a long session rather than discovering the cost afterwards.

**Live** is disabled until the camera has initialized; the grey `OFFLINE` box is the
placeholder before a stream starts.

### Stimulus Display

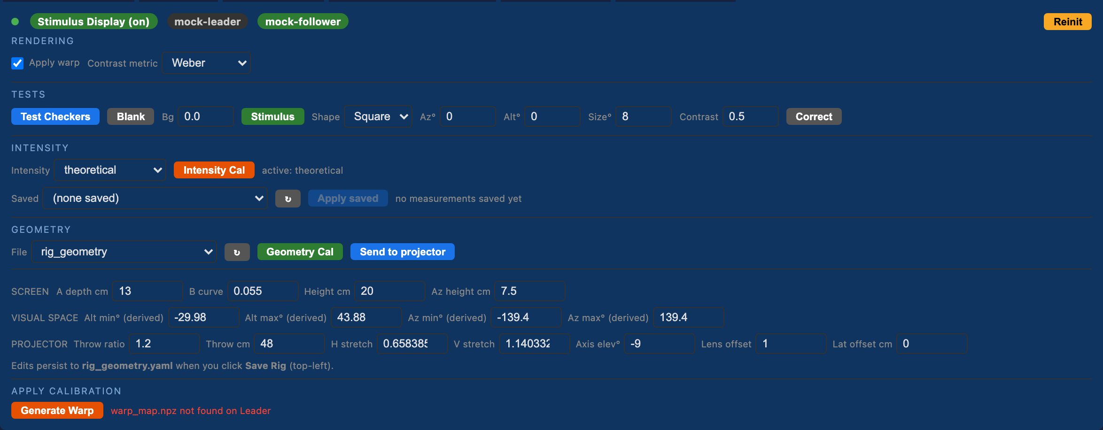
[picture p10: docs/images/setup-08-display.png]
Display card


The densest panel in the app, in four blocks:

- **RENDERING** — whether the warp map is applied, and which contrast metric the rig
  authors in (Weber / Michelson / Normalized). Changing the metric reinterprets every
  existing task YAML, so set it once per rig.
- **TESTS** — **Test Checkers** for focus and geometry, **Blank** to set the background
  to a plain 0–1 gray, **Stimulus** to place a patch at an azimuth/altitude. **Correct**
  clamps the typed contrast to what the display can actually reach at that background.
- **CALIBRATION** — **Calibrate** opens the landmark tool (below); **Intensity** selects
  the luminance-correction mode.
- **GEOMETRY** — the screen/projector model. The four **VISUAL SPACE** fields are
  derived, not editable: altitudes are computed in the browser, azimuths are ray-traced
  by the server as you type. Edits here are written when you press **Save Rig**.

### Reward Valve

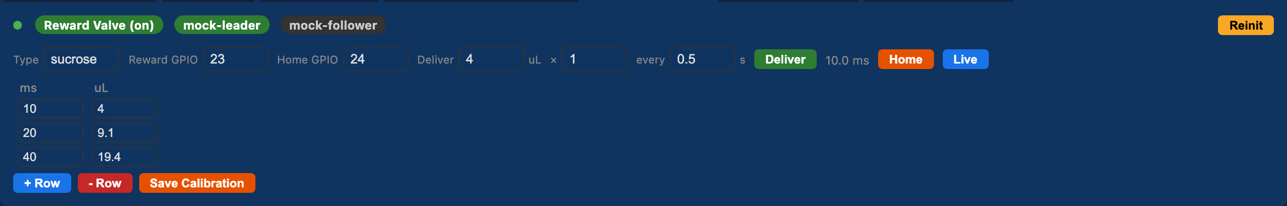
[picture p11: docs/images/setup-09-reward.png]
Reward card


Set the GPIO pins, then build the **ms → µL** calibration table with **+ Row**, and press
**Save Calibration**. **Deliver** interpolates the pulse width for the requested volume
and fires it *n* times at the given interval — that is how you prime the line and verify
the table. The **Home** button only appears if a home pin is configured. Full procedure:
[CALIBRATION_PROTOCOL.md](CALIBRATION_PROTOCOL.md).

### Lick Sensor

Lick sensor card

Set the I²C address (`0x5A`) and the electrode channel, press **Live**, and touch the
spout — ticks appear on the 30-second raster and *Last lick* updates. If nothing
registers, confirm the electrode number matches the wiring before suspecting the sensor.

### Photodiode

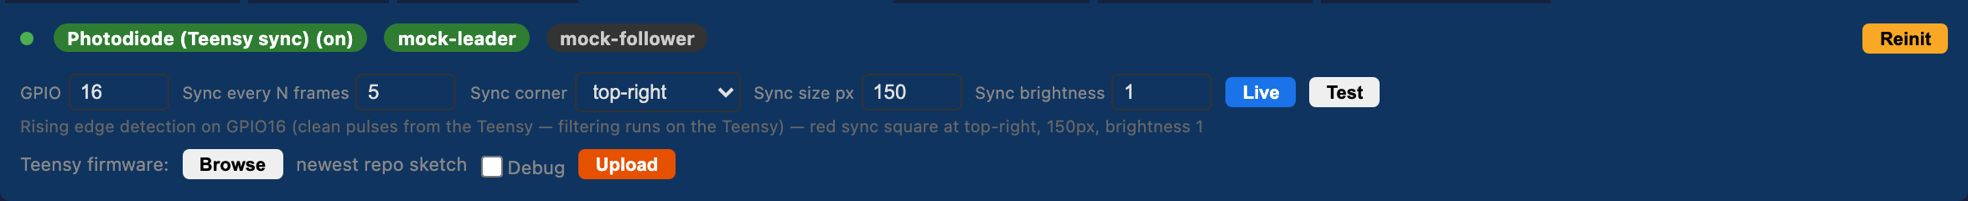
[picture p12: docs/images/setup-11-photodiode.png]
Photodiode card


The photodiode timestamps sync pulses from the Teensy. The `Sync ...` fields are authored
here but consumed by the **display** — they control the red patch the projector draws.
**Live** shows a triggered scope (−2 ms to +14 ms); **Test** additionally tells the
display Pi to start flashing the patch, so you can confirm the whole optical path in one
click. Filtering now lives on the Teensy, so there are no debounce sliders.

**Teensy firmware** (row under the card, usable before the device is initialized): **Browse** a
local `.ino` or leave it on the newest repo sketch, tick **Debug** for the serial traces, **Upload**.
The sketch is compiled and flashed on the Pi that owns the photodiode (named in the row), where the
Teensy is plugged in; the toolchain is installed there first if missing. A fresh Teensy (RawHID) is
rebooted over HID into its bootloader, so no button press is needed. Details:
[TEENSY_INSTRUCTIONS.md](TEENSY_INSTRUCTIONS.md).

### Running Wheel

Encoder card

I²C magnetic encoder. Set the wheel diameter (it scales cm/s and distance) and the sample
rate, then **Live** and spin the wheel.

### Calibration Probe

Calibration probe card

A single GPIO that **latches** high or low — a TTL marker for aligning an external
recording to a calibration session. It is driven automatically by the geometry
calibration; the button is for testing.

---

## Geometry calibration and the warp map

The rig is **rear-projected** onto a curved screen, so a stimulus at a requested azimuth
only lands correctly once the geometry is registered and a warp map is built.

1. In **CALIBRATION**, press **Calibrate**. The follower's X server restarts, the probe
   latches HIGH, and a popup opens the landmark tool served from the Pi at port `5091`.
2. Register the landmarks there and press its Save — the result posts back and is written
   as a timestamped `rig_geometry_<date>.yaml` alongside the canonical file.
3. Press **↻** to refresh the **File** list, pick the new geometry.
4. Press **Generate Warp**. The controller computes `warp_map.npz` locally, copies it to
   every Pi and asks each to reload it. The status line flips to a green
   *"warp_map.npz found on Leader"*.

**Send to projector** pushes a geometry file to the display Pi without regenerating the
warp — useful when only the model changed. Parameter meanings are in
[display_calibration/geometry_params.md](../display_calibration/geometry_params.md);
the full procedure is in [CALIBRATION_PROTOCOL.md](CALIBRATION_PROTOCOL.md).

## Intensity calibration

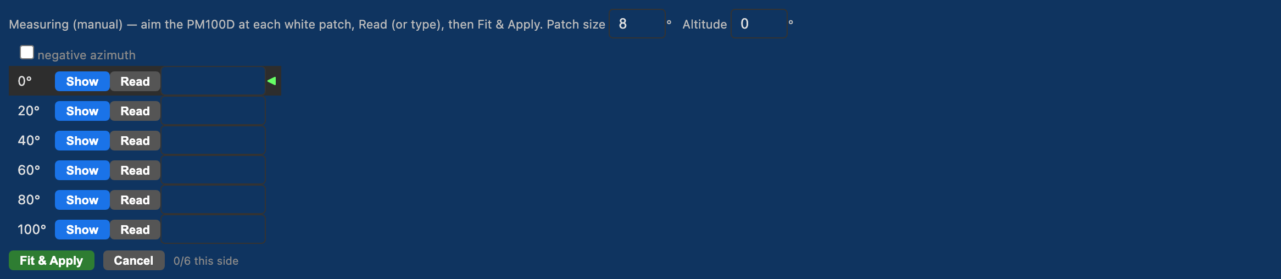
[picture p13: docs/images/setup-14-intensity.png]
Intensity calibration panel


The projector is brighter at the centre than at the edges, its light is not proportional to its
drive, and drive 0 still leaves a black floor. One intensity calibration measures all of it, and
the light model built from it makes the background uniform in light and defines brightness and
contrast on light (details: [CALIBRATION_PROTOCOL.md, Part 2](CALIBRATION_PROTOCOL.md)).

- **Calibration** lists the rig's files: measured ones, and the `theoretical` (geometry model, the
  default) and `none` mocks. **Apply** rebuilds and deploys the warp with the selected file and
  makes it the rig's (`devices.display.intensity_calibration`, saved at once). The line below shows
  the uniform range Bg 0..1 spans.
- **Measure…** opens the measurement panel, at one **Alt** for the whole calibration. One column
  per azimuth (0°, 40°, 80° by default; edit the header, **+ column**, × to remove — two columns
  minimum, three or more out to the screen edge recommended): light at drive 1.0 … 0.0 there
  (**+ level** / × edit the rows; 1.0 and 0.0 stay). ▶ shows a cell's patch (raw), R reads the
  Thorlabs PM100D and advances, or type the value. **Save** writes
  `display_calibration/<rig>/intensity/intensity_cal_<stamp>.yaml` and logs a fit report;
  **Save & Apply** also applies it.
- The TESTS row follows the applied calibration: **Bg** is a brightness, **Contrast %** is contrast
  of light, and the row shows the background's and the stimulus's light plus the drive at the test
  azimuth.

---

## Running without a rig

`rigs/demo.yaml` (created from the tracked `rigs/_demo_template.yaml` by the smoke test) plus `tools/mock_pi.py` gives a fully interactive UI with no hardware —
useful for demos, for finding your way around, and for regenerating these screenshots.
Both of its Pis are `127.0.0.1`, so a mis-click cannot reach the real rig.

```bash
python tools/mock_pi.py     # fake pi_api on :5080
python controller/app.py    # Setup tab -> Load rig -> demo -> Initialize
```

What does not work under the mock: Install / Reboot / Shutdown (real SSH), Generate Warp
and Intensity Cal (they compute locally, then fail at the copy step), the camera preview
(the mock serves no MJPEG), and the warp status, which always reads *not found*.

---

## Troubleshooting

| Symptom | Cause / fix |
|---|---|
| Everything greyed out | No rig loaded — **Load Rig** first |
| **Initialize** stays disabled | At least one Pi is not answering on port 5080. Press **Check**; then `sudo systemctl status vrfarm` on the Pi |
| Device card says *"Waiting for Pi check..."* | Same cause — the panel unlocks only after a successful Initialize |
| Devices go grey by themselves | You pressed **Deploy** or **Restart API**. Press **Initialize** again |
| *"SSH FAIL, API OK"* | The key or `known_hosts` entry is missing. Only **Install** needs SSH — see [CONTROLLER_SETUP.md §2](CONTROLLER_SETUP.md#2-passwordless-ssh-to-the-pis) |
| Install fails on a `sudo` step | `vruser` needs passwordless sudo — [INITIAL_SETUP_REFERENCE.md](INITIAL_SETUP_REFERENCE.md#new-pi-first-boot-headless-bring-up) step 5 |
| A device won't initialize | Confirm it is assigned to a Pi (click the Pi chip in its card), then check pins and packages |
| Camera preview is a broken image | Expected under the mock. On the real rig, press **Stop** then **Live**, or **Reinit** the camera |
| Warp status red on a working rig | `/api/check_warp` looks only on the Pi with `role: leader` |
| Edits vanished | You did not press **Save Rig** |

---

**Next:** [Experiment UI](EXPERIMENT_UI.md) · [Calibration protocol](CALIBRATION_PROTOCOL.md) · [Docs index](README.md)

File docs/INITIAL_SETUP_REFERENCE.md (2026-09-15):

# VRFarm — Environment Setup Reference

**Project:** VRFarm
**Last updated:** 2026-08-11
**Current rig:** `rigs/cheddar.yaml` — rig `cheddar`, hosts `cheddar` (Leader) and
`cheddar-dlp` (Follower). The UI lists rigs by filename, so it appears as `cheddar`.

This is the first-time **rig bring-up** reference: hardware, network/IPs, OS, conda
Pi bring-up, envs, package installs, GPIO (lgpio), projector startup, systemd service, SSH keys, gotchas.
For the **controller** machine (the macOS/Linux box running the UIs) the authoritative doc
is `docs/CONTROLLER_SETUP.md`; the Controller section here is a short version of it.

Most of the per-Pi package/service work below is automated by the setup UI's **Install**
button (`controller/setup.py` -> `api_install_pi`). Do it by hand only when reflashing an SD card
or debugging Install — the manual steps document what Install does under the hood.

---

## Overview

| Machine | Role | Conda env | IP |
|---|---|---|---|
| Controller (macOS/Ubuntu) | UI + data storage | `vrfarm` | 192.168.10.1 |
| Leader | Leader Pi — imperative trial loop + GPIO devices | `rig` | 192.168.10.101 |
| Follower | Follower Pi — pygame display | `rig` | 192.168.10.102 |
| Switch (Zyxel XGS1210-12) | experiment switch; web UI on port 80 | — | 192.168.10.254 |

Both Pis run **Debian 13 (trixie)**, user `vruser`, conda base at `~/miniforge3`.
The `rig` env Python **must match the system Python** (3.13 on trixie) — see the
conda note under each Pi.

> **Bringing up a new or reflashed Pi?** Start with
> [New Pi first boot](#new-pi-first-boot-headless-bring-up) (SSH, WiFi, static IP, sudo),
> then run the setup UI's **Install → Deploy**.

---

## Controller Setup

Short version; full detail (Ubuntu netplan, firewall, `$VRFARM_DATA_DIR`) is in
`docs/CONTROLLER_SETUP.md`.

### Conda environment

```bash
conda create -n vrfarm python=3.11 -y
conda activate vrfarm
pip install flask requests scipy matplotlib numpy h5py pyyaml
```

`paramiko` and `pyzmq` are no longer needed (replaced by REST API + UDP). `picamera2`
and `lgpio` live on the Pis, not here.

### Project folder

```
~/VRFarm/
├── experiments/*.yaml                 <- task/paradigm configs (stimulus/reward/session/adaptive)
├── rigs/cheddar.yaml                   <- rig hardware config (pins, cal, roles, IPs)
├── devices/                            <- device abstraction layer (one file per device)
├── engine/                             <- trial loop: leader.py
├── displayd/                           <- KMS display daemon + renderer child (follower)
├── controller/                         <- the controller UI (localhost:5000): Network / Setup / Experiment / Data
├── pi_api/api.py                       <- Pi REST API (deployed to each Pi)
├── shared/                             <- config loaders, stim generator, consolidate
├── display_calibration/                <- projector geometry + warp scripts (kmsdrm)
├── data/                               <- transferred session data (auto-created; $VRFARM_DATA_DIR override)
└── docs/                               <- documentation
```

Session data lands in `$VRFARM_DATA_DIR` (if set) else `~/VRFarm/data`; there is no
controller path in the rig yaml (see `docs/CONTROLLER_SETUP.md` §3b).

### Passwordless SSH (required for the setup UI's deploy/calibrate)

```bash
ssh-keygen -t ed25519          # skip if you already have a key
ssh-copy-id vruser@192.168.10.101   # leader
ssh-copy-id vruser@192.168.10.102   # follower

# Test — seeds known_hosts, which the non-interactive setup UI needs
ssh vruser@192.168.10.101 echo "leader OK"
ssh vruser@192.168.10.102 echo "follower OK"
```

The Experiment tab uses no SSH — the Setup tab (install, warp push, reboot, calibrate) and the
Data tab (rsync sync, purge, power off) do. Every new controller must add **its own** key to the Pis.

---

## New Pi first boot (headless bring-up)

Getting a fresh Pi onto the rig — the steps we used replacing the Leader with a Pi 5 (still the
Leader, still at `192.168.10.101`). A fresh Raspberry Pi OS / Debian image usually boots with
**SSH off** and only on WiFi (or a stray address), **not** on the experiment switch, so these steps
get it reachable and onto the switch. Skip any that are already done.

### 1. Enable SSH (fresh image)

Needs console access the first time (monitor+keyboard), or preset it in Raspberry Pi Imager:
```bash
# on the Pi:
sudo systemctl enable --now ssh          # SSH on now + at boot
# equivalently: sudo raspi-config -> Interface Options -> SSH -> Yes
```
Headless alternative: reflash with the Imager and, under ⚙ *Edit Settings*, set the hostname, enable
SSH with the controller's public key, the `vruser` account, and WiFi — then it boots ready.

### 2. WiFi — for internet + NTP (NetworkManager)

```bash
nmcli radio wifi on
nmcli device wifi list                                    # find the SSID
sudo nmcli device wifi connect "<SSID>" password "<PW>"   # OPEN network: omit `password ...` entirely
ping -c1 8.8.8.8 && getent hosts deb.debian.org && echo "internet OK"
```
Caveat: the institute `public` WiFi is a captive-portal/firewalled net — it **associates but has no
egress**. NTP may still pass; for package installs with no egress, route apt/pip/conda through an HTTP
proxy on the controller (the Pi reaches it over the switch at `192.168.10.1`).

### 3. Static IP on the switch (eth0)

Give the wired interface the fleet address; no gateway/DNS on eth0 — WiFi stays the internet path:
```bash
sudo nmcli connection modify "Wired connection 1" \
  ipv4.method manual ipv4.addresses 192.168.10.101/24 \
  ipv4.gateway "" ipv4.dns "" ipv4.never-default yes
sudo nmcli connection up "Wired connection 1"
ip -br addr show eth0                        # expect 192.168.10.101/24  (Follower = .102)
```
Do this from a monitor or over WiFi — changing `eth0` drops an `eth0` SSH session.

### 4. Passwordless SSH from the controller

```bash
# on the controller:
ls ~/.ssh/id_*.pub || ssh-keygen -t ed25519     # make a key if you have none
ssh-copy-id vruser@192.168.10.101               # enter the Pi password once
ssh vruser@192.168.10.101 hostname              # prints the hostname, no password
```
**Reused IP → `REMOTE HOST IDENTIFICATION HAS CHANGED`?** A rebuilt/replaced Pi at the same IP has a
new host key. Clear the stale entry and retry (safe when it's your own Pi):
```bash
ssh-keygen -R 192.168.10.101
ssh-copy-id vruser@192.168.10.101
```

### 5. Passwordless sudo (the setup UI's Install needs it)

Install runs `sudo apt`, `raspi-config`, etc. **non-interactively over SSH**, so `vruser` must have
**passwordless sudo** — otherwise Install fails with `sudo: a terminal is required to read the password`.
Images flashed with the Pi Imager's user preset usually have it; a hand-created user often doesn't. Add
it (enter the password this once):
```bash
echo "vruser ALL=(ALL) NOPASSWD:ALL" | sudo tee /etc/sudoers.d/010_vruser-nopasswd >/dev/null
sudo chmod 440 /etc/sudoers.d/010_vruser-nopasswd
sudo visudo -c                      # verify sudoers syntax
sudo -n true && echo "passwordless sudo OK"
```

### 6. Time zone

Install sets it on every Pi, so leader and follower logs show the same local time (recorded data
is Unix time regardless). By hand:
```bash
sudo timedatectl set-timezone Europe/Vienna
timedatectl | grep "Time zone"
```

### Pi 5 notes
- Boots from **NVMe SSD** — no more tiny-SD-card churn; video can live on the NVMe.
- **GPIO is lgpio, not pigpio** (Pi 5's RP1 GPIO — `pigpio`/`pigpiod` don't work). No daemon; see the
  GPIO section below. Header controller is `gpiochip0` on current OS (`gpiodetect` to confirm; set
  `gpiochip: 4` on the device in the rig YAML (`rigs/<rig>.yaml`) only on very early Pi 5 images).
- The setup UI **Install** needs **miniforge already present** (`~/miniforge3`); it creates the `rig`
  env but doesn't install conda itself.

---

## Leader Pi Setup

Everything below is what the setup UI **Install** does automatically; do it by hand only
for a fresh SD card. The Leader owns the behavioral devices: lick sensor, reward,
photodiode (Teensy-fed sync pulse), camera, and the running-wheel encoder.

### Conda environment

The `rig` env Python must equal the **system** Python (trixie = 3.13) — the camera
bindings (`python3-libcamera`/`python3-picamera2`) are apt-built for the system Python
and symlinked into the env, so a mismatch breaks `import picamera2`.

```bash
conda create -n rig python=$(python3 -c 'import sys;print(f"{sys.version_info[0]}.{sys.version_info[1]}")') -y
conda activate rig
```

### Python packages (pip, into the `rig` env)

Base plus the packages for whichever devices this Pi runs (Install picks these per the
rig's device list):

```bash
pip install flask pyyaml numpy h5py       # base + leader (h5py)
pip install smbus2                          # lick_sensor
pip install lgpio scipy                     # reward
pip install lgpio                           # photodiode + calibration probe
pip install pillow simplejpeg piexif av     # camera (plus h5py)
```

### Camera bindings (apt + symlink, only if camera enabled)

Not a pip install — the bindings are apt packages symlinked into the conda env:

```bash
sudo apt-get install -y python3-libcamera python3-picamera2
# Install then symlinks libcamera/picamera2/pykms/pidng/videodev2/prctl into the rig
# env's site-packages. The env Python minor version MUST equal system Python or the
# compiled .so bindings have the wrong ABI and import fails.
```

### GPIO — lgpio (reward / photodiode / calibration probe)

GPIO uses **lgpio**, which works on Pi 5 (RP1) and Pi 4 (BCM). There is **no daemon** and nothing to
enable on boot — it talks to `/dev/gpiochip*` directly (this replaced `pigpio`/`pigpiod`, which do
**not** work on the Pi 5). `pip install lgpio` **builds from source and needs `swig`**, so Install
uses the apt binding + symlink instead (same pattern as the camera bindings): `sudo apt install -y
python3-lgpio`, then symlink `lgpio.py` + `_lgpio*.so` from `/usr/lib/python3/dist-packages` into the
rig env (env Python must == system Python). Verify:

```bash
python3 -c "import lgpio; h=lgpio.gpiochip_open(0); print('gpiochip0 ok', h); lgpio.gpiochip_close(h)"
gpiodetect        # the 40-pin header controller should be 'pinctrl-rp1' (Pi 5) or 'pinctrl-bcm...' (Pi 4)
```

The device code opens `gpiochip0` by default (correct for Pi 5 on current OS and for Pi 4). Only very
early Pi 5 images exposed the header as `gpiochip4` — if a GPIO claim fails, set `gpiochip: 4` on the
device in the rig YAML (`rigs/<rig>.yaml`).

### SSD mount for video

Camera video (H.264) writes to the rig yaml's `data.video_dir`. The default is
`/media/vruser/ssd/video` (an external SSD, because the leader's SD card is too full to
hold video). `rigs/cheddar.yaml` instead uses `/home/vruser/video`, a plain folder on the
leader's boot NVMe — the Pi 5 boots from NVMe, so it needs no separate video drive.
If you use an external SSD:

```bash
sudo mkdir -p /media/vruser/ssd
sudo mount /dev/sda1 /media/vruser/ssd
sudo chown vruser:vruser /media/vruser/ssd
echo "/dev/sda1 /media/vruser/ssd ext4 defaults,nofail 0 2" | sudo tee -a /etc/fstab
```

Then name the mountpoint next to `video_dir` in the rig YAML, so the Data tab trusts (and purges)
the video tree only while the drive is mounted:

```yaml
data:
  video_dir: /media/vruser/ssd/video
  video_mount: /media/vruser/ssd
```

Leave `video_mount` out when video lives on the boot disk, as on cheddar. See
`docs/MULTI_RIG.md` → Sessions without video.

### Folder structure on Pi

```
~/rig/                      <- code deployed here (setup UI Deploy)
~/data/<subj>/<subj_date>/<session_id>/   <- HDF5 + sidecars per session (transferred after)
<data.video_dir>/<subj>/<subj_date>/      <- video recordings
```

When the Data tab syncs a session (or at the leader's own exit) the sidecars are folded into one consolidated `<session_id>.h5`
(see `docs/DATA_FORMAT.md`).

---

## Follower Pi Setup

The Follower runs only the pygame display (over the DLP projector). Install handles the
packages, code, and systemd service; the manual steps here are for a fresh card.

### System packages (X11)

```bash
sudo apt install -y libx11-dev libxext-dev libxi-dev \
  xserver-xorg-core libgl1-mesa-dri libglu1-mesa mesa-utils
```

### Conda environment

```bash
conda create -n rig python=$(python3 -c 'import sys;print(f"{sys.version_info[0]}.{sys.version_info[1]}")') -y
conda activate rig
pip install flask pyyaml numpy pygame
```

PsychoPy is not used — pygame handles all rendering.

### X11 configuration

Must use the modesetting driver for 24-bit visuals and V3D hardware GL.

```bash
sudo tee /etc/X11/xorg.conf > /dev/null << 'EOF'
Section "Device"
    Identifier "drm"
    Driver "modesetting"
EndSection

Section "Screen"
    Identifier "Default Screen"
    Device "drm"
    DefaultDepth 24
    SubSection "Display"
        Depth 24
    EndSubSection
EndSection
EOF
```

### Projector startup

The DLP projector connects via DPI GPIO. Under full KMS there is **no startup script and no
X server**: `displayd.service` brings the projector up at boot and keeps it up, walking
BOOT → CONFIG_OK → DLPC_ALIVE → VIDEO_UP → DLPC_LOCKED → CURTAIN_DOWN → RENDERER_UP. Force a
re-walk with `curl -sX POST http://127.0.0.1:5581/bringup` on the follower; the setup UI's
**Init Devices** and the Display card's **Reinit** both route there. Historically this was
`start_projector.sh`, which also started X — deleted in phase 4. What bring-up does:

1. **CONFIG_OK** — the `DPI-1` connector exists and our 1920x1080@57.46 mode is listed.
   Under full KMS the pin muxing is the kernel's job (`vc4-kms-dpi-generic` in
   `config.txt`), so there is no `pinctrl set ... a2` loop any more.
2. **DLPC_ALIVE** — the DLPC3436 answers on the bit-banged I2C bus (GPIO23/22, addr 0x36).
3. **VIDEO_UP** — TI's flash-select tri-state preamble, then the RGB666 parallel buffer is
   enabled (this is what GPIO25-high used to do).
4. **DLPC_LOCKED** — source set to external parallel, sync polarity negotiated
   (hsync-invert, vsync-invert on this rig), lock confirmed by readback.
5. **CURTAIN_DOWN** — image curtain lifted.
6. **RENDERER_UP** — the renderer child is spawned on the system python3, takes DRM
   master, and must pass its self-test (KMSDRM backend, 57.46 fps, blocking flip).

**No X server is started at any point**, and none may be: X would take DRM master away
from the renderer and black the projector.

displayd drives the DLPC through `displayd/dlpc.py`, which wraps the **vendored TI DLPC SDK
in this repo's `dlp/`**, which the setup UI pushes to `~/dlp/` via scp on Deploy (follower
only — `~/dlp` sits outside `~/rig`, so it rides scp, not the REST upload). A reflashed card
gets it back on the next Deploy.

**Two prerequisites**, both handled by **Install → Deploy** — do them before running the script
by hand, or `cd ~/dlp` fails and the DLPC never initializes:
- **`~/dlp/` must exist** — it lands on the first **Deploy** (follower). A fresh card has no
  `~/dlp` until then.
- **I²C must be enabled** — `init_parallel_mode.py` drives the DLPC over `/dev/i2c-*` (raw
  `fcntl.ioctl` in `dlp/linuxi2c.py` — **no `smbus2` needed**). Install runs
  `sudo raspi-config nonint do_i2c 0` for the follower; by hand: enable I²C in `raspi-config`.

### Folder structure on Pi

```
~/rig/                          <- code deployed here (setup UI Deploy)
~/rig/calibration/              <- warp_map.npz, rig_geometry.yaml, calib tools
~/rig/stims/<session_id>/       <- pre-generated stim NPZ (pushed by Leader at deploy)
~/dlp/                          <- DLPC init SDK (vendored, pushed via scp on Deploy)
```

---

## Deploy Code to Pis

Use the rig setup UI:

```bash
conda activate vrfarm
cd ~/VRFarm
python controller/app.py    # opens localhost:5000 -> Setup tab
```

1. **Load Rig** (`cheddar`) — also checks SSH + the REST API on each Pi (`/api/status`)
   automatically. There is no separate Connect button; the per-Pi **Check** button re-runs it.
2. **Install** (first time, via SSH): ensures the `rig` conda env matched to system
   Python, installs the device-specific apt/pip packages, symlinks the camera and lgpio
   bindings, uploads the code, pushes `~/dlp/` to the follower, and installs + enables the
   `vrfarm` systemd service (lgpio needs no daemon). Reboot the follower afterwards.
3. **Deploy** (via REST API): re-uploads the code files and restarts `pi_api` so the new
   code runs; the follower also gets `displayd/` and the calibration tools.
4. **Initialize** — initializes each enabled device on its Pi (projector + display,
   lick, reward, camera, photodiode, encoder). It is disabled until every Pi is green, and
   **Deploy / Restart API reset it**, so re-press it after either.

Full walkthrough with screenshots: [SETUP_UI.md](SETUP_UI.md).

### systemd service

Each Pi runs `pi_api/api.py` as the `vrfarm` service (unit `pi_api/vrfarm.service`) on
port 5080, `Restart=always`, launched with the `rig` env Python from `/home/vruser/rig`:

```bash
# Status / restart:
ssh vruser@192.168.10.101 "sudo systemctl status vrfarm"
ssh vruser@192.168.10.101 "sudo systemctl restart vrfarm"
```

The setup UI can restart `pi_api` remotely (`/api/restart`, used automatically after
Deploy) — it self-kills and systemd respawns it with the new code.

---

## Running Experiments

```bash
conda activate vrfarm
cd ~/VRFarm
python controller/app.py    # localhost:5000 -> Experiment tab
```

Workflow: **Load rig -> Connect -> Load Experiment -> Deploy -> GO -> (STOP) -> New session**,
then the Data tab to sync ([MULTI_RIG.md](MULTI_RIG.md)).
An optional `VRFARM_SLACK_WEBHOOK` env var enables Slack start/end/timeout notifications.
See [EXPERIMENT_PROTOCOL.md](EXPERIMENT_PROTOCOL.md) for the scientific protocol and
[EXPERIMENT_UI.md](EXPERIMENT_UI.md) for the interface itself.

---

## NTP Clock Sync

All timestamps are `time.time()` Unix seconds and must share a common clock.

### Each Pi — sync to internet NTP

```bash
sudo apt install chrony -y
chronyc tracking
# "System time" should be <1ms offset
```

The Pis reach NTP over their WiFi (`wlan0`); the wired experiment switch has no route out.

---

## Network Layout

```
Zyxel XGS1210-12 switch (experiment traffic)   web UI 192.168.10.254 (static; factory 192.168.1.3)
├── port 11   10G SFP+ (DAC)  Controller  192.168.10.1    (fystyk: Intel 82599ES, netplan rig0)
├── ports 1-2 1G RJ45         Leader      192.168.10.101  (eth0 static)
│                             Follower    192.168.10.102  (eth0 static)
└── port 12   10G SFP+        spare, reserved for a second switch

Both Pis also on institute WiFi (wlan0) for internet/NTP; WiFi stays the default route.
Addresses: .1 controller · .101-.250 rig IP pairs (Network tab) · .251-.254 infrastructure.
```

UDP / TCP ports:
- 5571: Leader -> controller (events) — must be open inbound on the controller
- 5572: controller -> Leader (commands; first packet teaches the Leader the return address)
- 5575: Leader -> Follower (display commands)
- 5080: REST API on each Pi (HTTP)
- 80: switch web UI at 192.168.10.254

The per-Pi onboarding steps (SSH, WiFi, static IP, sudo) live in
[New Pi first boot](#new-pi-first-boot-headless-bring-up) above.

---

## Dependency Summary

| Package | Controller | Leader | Follower |
|---|---|---|---|
| Python | 3.11 | match system (3.13 trixie) | match system (3.13 trixie) |
| flask | yes | yes | yes |
| requests | yes | — | — |
| numpy | yes | yes | yes |
| scipy | yes | yes (reward) | — |
| matplotlib | yes | — | — |
| h5py | yes | yes | — |
| pyyaml | yes | yes | yes |
| pygame | — | — | yes |
| smbus2 | — | yes (lick) | — |
| lgpio | — | yes (reward/photodiode/probe) | — |
| pillow, simplejpeg, piexif, av | — | yes (camera) | — |
| python3-picamera2 + python3-libcamera (apt, symlinked) | — | yes (camera) | — |
| chrony (apt) | — | yes | yes |
| xserver-xorg / libgl (apt) | — | — | yes |

No longer needed: `paramiko`, `pyzmq`, `psychopy`, `pyglet`, `psychtoolbox`, `libcap-dev`
(camera is apt `python3-picamera2` now, not a pip build).

---

## Troubleshooting Quick Reference

| Problem | Fix |
|---|---|
| SSH connect fails | `ssh-copy-id vruser@<ip>` (and `ssh` once to seed known_hosts) |
| REST API not responding | `sudo systemctl restart vrfarm` on Pi |
| GPIO device won't init / claim fails | check wiring; confirm the header is `gpiochip0` (`gpiodetect`); set `gpiochip: 4` in the rig only on early Pi 5 images |
| `import picamera2` fails | rig env Python must equal system Python (3.13); recreate env, re-run Install |
| pygame renders nothing, no error | wrong interpreter — the display must run on **system** `/usr/bin/python3`; the conda env's SDL has no kmsdrm backend and falls back to a null driver |
| Projector black / no image | `curl :5581/status` on the follower; if not `RENDERER_UP`, `curl -sX POST :5581/bringup`. Check no X or stray DRM client is running |
| Clock drift between Pis | `sudo systemctl restart chrony` |
| SSD not mounting | check `lsblk`, verify `/etc/fstab` entry |
| Warp map not found | Generate Warp in the setup UI (built on the controller, scp'd to `~/rig/calibration/warp_map.npz`) |
| Pi can't reach the internet to install | Pis are firewall-gated off `public` WiFi; run an HTTP proxy on the controller (`python -m proxy --hostname 192.168.10.1 --port 8899`) and `export HTTPS_PROXY=http://192.168.10.1:8899` on the Pi |
| Leader SD card full | tiny ~8 GB card; reclaim with `conda clean -a -y` and `pip cache purge` |
| Port 5000 taken on a macOS controller | disable AirPlay Receiver (System Settings -> General -> AirDrop & Handoff) |
| conda not in SSH PATH | `source ~/miniforge3/etc/profile.d/conda.sh && conda activate rig` |
</content>
</invoke>

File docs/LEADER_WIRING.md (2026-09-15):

# Leader — Hardware Wiring Reference

Pin assignments for **the Leader Pi** on rig **cheddar** (192.168.10.101).
Source of truth for the live pins is `rigs/cheddar.yaml` on the controller — untracked (it
carries the rig's Slack webhook), so it has no copy in git — if you change a pin there,
update this table. The **Future expansion** section below reserves pins on paper for
hardware not yet wired (no device class yet, so nothing is in the rig YAML for those rows).

**GPIO numbering is BCM**, not physical pin position. The 40-pin header pinout is
**identical on Pi 4B and Pi 5**, so this map holds for either board — only the GPIO
*library* differs (see [Software prerequisites](#software-prerequisites)).

---

## Currently wired

| Device | Signal | Dir | BCM GPIO | Phys | Config key | Notes |
|---|---|---|---|---|---|---|
| Reward valve  | Main solenoid | OUT | **23** | 16 | `devices.reward.pins.main.gpio` | Active-high pulse; gate of a FET/driver, not the valve supply. Boots LOW. |
| Reward valve  | Home solenoid | OUT | **24** | 18 | `devices.reward.pins.home.gpio` | Second valve line, same driver pattern. Boots LOW. |
| Photodiode | Sync pulse (Teensy) | IN | **16**  | 36 | `devices.photodiode.gpio` | Clean 3.3 V square pulse from the **Teensy** (below) — one rising edge per sync frame. No on-Pi filtering. |
| Lick sensor | MPR121 SDA/SCL  | I²C-1 | **2 / 3**| 3/5  | `devices.lick_sensor.i2c_address` `0x5A` | Touch electrode 4 on the MPR121, not a Pi GPIO. Shares the bus (below). |
| Wheel encoder | AS5600 SDA/SCL  | I²C-1 | **2 / 3**| 3/5  | `devices.encoder.i2c_address` `0x36` | Magnetic angle sensor on the running wheel. Same bus as the lick sensor (below). |
| Camera | CSI ribbon | CSI | — | CSI  | `devices.camera` | Flat ribbon to the CSI connector, not the GPIO header. |

> The **stimulus display** lives on **the Follower Pi** (192.168.10.102) over
> HDMI/DPI — nothing on the leader's header. The photodiode is taped over the sync patch on
> the follower's screen; its analog signal runs to a **Teensy**, and only the Teensy's clean
> digital pulse returns to **the leader's GPIO16**.

> **Retired:** the `calibration_probe` TTL output (was GPIO22) is no longer a device —
> GPIO22 is a free spare. Reward moved off GPIO17/18 to **23/24**, freeing 17/18 too.

### Photodiode signal conditioning — the Teensy

The photodiode swings **>5 V**, which is unsafe both for the Pi (3.3 V, not 5 V-tolerant)
and for a naïve threshold. A **Teensy 4** sits between the photodiode and the leader and does
all the conditioning — the leader just timestamps the resulting clean edges.

| Teensy pin | Signal | Notes |
|---|---|---|
| **A1** (analog in) | ← photodiode | **Divide/clamp to ≤ 3.3 V before this pin** — Teensy 4 analog pins are 3.3 V max, not 5 V-tolerant. |
| **pin 16** (OUT) | → Leader **GPIO16** | Clean **5 ms** (`OUT_PULSE_US`), 3.3 V square pulse per sync frame; idles LOW, pulses HIGH. Drives the Pi input directly (no level shift). |
| **pin 13** (LED)| onboard LED mirrors OUT | Quick visual check that pulses are firing — **`DEBUG` builds only**. |
| **GND** | ↔ Leader GND | Common ground is essential — tie Teensy GND to a Pi GND pin. |
| USB | power | Bench supply or a Pi USB port. |

Firmware: [`teensy/photodiode_sync_v2_0/`](../teensy/photodiode_sync_v2_0/) — build, flash
and tuning instructions in **[TEENSY_INSTRUCTIONS.md](TEENSY_INSTRUCTIONS.md)**. It is a
Schmitt trigger plus the same two filters the old on-Pi model used (`STEADY_US = 150` glitch
reject, `HOLDOFF_US = 5000` → one pulse per frame). Since v2_0 the two thresholds are
**adaptive** by default (`ADAPTIVE = true`): they ride a live baseline/peak estimate so they
follow the diode's drifting idle level. Set `ADAPTIVE = false` for the fixed pair
(`THRESHOLD_HI_V = 1.8` / `THRESHOLD_LO_V = 0.6`). Flash with `DEBUG = 0` for production.

This **replaces the old on-Pi debounce/glitch model**: the
`debounce_*` / `glitch_*` keys still present in the rig YAML are now **inert**, and
`photodiode.py` explicitly clears the Pi glitch filter so the Teensy edges pass untouched.

### I²C bus (both sensors — daisy-chained)

Both sensors sit on the **one hardware I²C-1 bus** (GPIO2 = SDA, GPIO3 = SCL). Daisy-chain
them: run **3V3 / GND / SDA / SCL** from the header to the first breakout, then the same
four nets on to the second. This works only because the addresses differ:

| Sensor | Chip | Address | Role |
|---|---|---|---|
| Lick sensor | MPR121 | `0x5A`  | Capacitive touch (licks) |
| Wheel encoder | AS5600 | `0x36`  | Running-wheel angle |

- GPIO2/3 have **onboard ~1.8 kΩ pull-ups** to 3V3. Many breakouts add their own pull-ups
  too; two in parallel is usually fine at 100 kHz. If the bus looks marginal
  (`i2cdetect` flaky, NAKs), remove the pull-ups on **one** board.
- Verify both after wiring: `i2cdetect -y 1` should show **`5a`** and **`36`**.
- Keep the daisy-chain leads short; for a long run to the wheel, twist SDA/SCL with GND.

---

## Future expansion (reserved on paper)

Planned headroom: **+3 general-purpose TTL inputs** and **+3 TTL outputs**. Pins are chosen
below by the [selection rules](#gpio-selection-rules); they are **not** in the rig YAML
yet (no `ttl_in` / `ttl_out` device class exists — add one modeled on `photodiode.py` for
inputs and a latched-output helper for outputs, then register the pins).

| Line | Dir | BCM GPIO | Phys | Boot state | Why this pin |
|---|-----|---|---|---|---|
| TTL out 1  | OUT | **17** | 11 | LOW | Boot-low; freed when reward moved to 23/24. Reward-cluster neighbour, GND at phys 14. |
| TTL out 2  | OUT | **18** | 12 | LOW | Boot-low; also freed by the reward move. |
| TTL out 3  | OUT | **27** | 13 | LOW | Boot-low; completes the phys 11–13 output cluster beside GND phys 14. |
| TTL in 1 | IN  | **19** | 35 | LOW | Contiguous input block at the header end; GND at phys 39. |
| TTL in 2 | IN  | **20** | 38 | LOW | Same block. |
| TTL in 3 | IN  | **21** | 40 | LOW | Same block; GND at phys 39 adjacent. |

> ⚠️ **Pi GPIO is 3.3 V and NOT 5 V-tolerant.** Lab TTL sources (Master-8, Arduino, DAQ,
> BNC TTL) are usually **5 V** — feed the three TTL **inputs** through a level shifter,
> resistor divider, or (preferred) an **opto-isolator**, which also breaks ground loops.
> Pi **outputs** swing 0–3.3 V (most 5 V-logic inputs still read that as HIGH) and source
> ~8 mA safely — drive anything heavier (LED, relay, second solenoid) through a
> transistor/buffer, as the reward valve already is.

Software-wise the TTL inputs should follow the **photodiode pattern**: claim the line as an
input with a software pull-down + edge callback tagged with the hardware tick. TTL outputs
should follow the **reward pattern**: claim as output-low, then a latch or a pulse thread.

Still-free spares after this: **GPIO22** (phys 15, freed from the calibration probe), and
boot-LOW **GPIO12/13/25/26** (12 is PWM0, 13 is PWM1). **GPIO4/5/6** boot HIGH — use them
only as inputs/spares.

---

## Full 40-pin header map

```
                 3V3  (1) (2)  5V
      SDA  GPIO2  I²C  (3) (4)  5V
      SCL  GPIO3  I²C  (5) (6)  GND ──┐ sensor gnd
           GPIO4 spare (7) (8)  GPIO14  UART TXD (reserved)
                 GND  (9) (10) GPIO15  UART RXD (reserved)
 ttl-out1 GPIO17 OUT (11) (12) GPIO18  OUT  ttl-out 2
 ttl-out3 GPIO27 OUT (13) (14) GND
 spare    GPIO22  —  (15) (16) GPIO23  OUT  reward main
                 3V3 (17) (18) GPIO24  OUT  reward home
 SPI     GPIO10 rsvd (19) (20) GND
 SPI      GPIO9 rsvd (21) (22) GPIO25  spare (boot-low)
 SPI     GPIO11 rsvd (23) (24) GPIO8   SPI CE0 (reserved)
                 GND (25) (26) GPIO7   SPI CE1 (reserved)
 EEPROM   GPIO0 rsvd (27) (28) GPIO1   EEPROM  (reserved)
           GPIO5 spare(29)(30) GND
           GPIO6 spare(31)(32) GPIO12  spare (PWM0, boot-low)
          GPIO13 spare(33)(34) GND
 ttl-in1 GPIO19  IN  (35) (36) GPIO16  IN   photodiode (Teensy pulse)
          GPIO26 spare(37)(38) GPIO20  IN   ttl-in 2
                 GND (39) (40) GPIO21  IN   ttl-in 3
```

Legend: **OUT/IN** = wired or reserved signal · **I²C** = shared sensor bus ·
**rsvd** = kept free for a bus (SPI0 for a future photodiode ADC, UART console, HAT EEPROM) ·
**spare** = free for expansion.

---

## GPIO selection rules

Why the pins landed where they did — reuse these when adding hardware:

1. **Outputs must boot LOW.** GPIO **0–8 power up with pull-ups (float HIGH)**; GPIO
   **9–27 power up pull-down (LOW)**. Every output — both reward lines (23/24) and all
   reserved TTL-out (17/18/27) — is in 9–27 so a valve or marker can't glitch active before
   software claims the line.
2. **Don't squat on a bus you might want.** GPIO2/3 are I²C (in use). GPIO7–11 (SPI0) are
   left free for a possible **MCP3008 photodiode ADC** (analog sync trace + UI-adjustable
   threshold — an alternative to the Teensy front-end). GPIO0/1 (HAT ID EEPROM) and
   GPIO14/15 (serial console) are left alone.
3. **Group by function and hug a ground.** The reward pair sits on the right column
   (phys 16/18) next to GND phys 20; the three TTL inputs form a contiguous block at the
   header end (phys 35/38/40) beside GND phys 39; the reserved TTL outputs cluster at
   phys 11–13 beside GND phys 14 — short, tidy runs to a terminal block.
4. **One clean digital line per external signal.** The photodiode's analog conditioning
   lives on the Teensy; the leader sees only a boot-low digital input on GPIO16.

---

## Power / ground

- **3V3 logic only** on the header (phys 1/17). MPR121, AS5600, the Teensy output, and all
  TTL I/O must stay within 0–3.3 V. GPIO16 and the TTL-in pins are **not** 5 V-tolerant.
- The photodiode's **>5 V** analog swing is divided/clamped **on the Teensy side** (before
  its A1 pin) — the Pi never sees it. Tie the Teensy GND to a Pi GND pin.
- Tie every device ground to a Pi **GND** pin (phys 6, 9, 14, 20, 25, 30, 34, or 39).
  Use a common star ground; opto-isolate external TTL to avoid ground loops.
- The reward solenoids run off a **separate supply** through a transistor/FET + flyback
  diode — GPIO23/24 only switch the gate, they do not power the valves.

> **Planned: breakout PCB.** A future hat/breakout board is the intended home for all of
> this — a ground plane retires the star-ground juggling, and the same board consolidates
> the signal conditioning this doc calls out per-line: I²C pull-ups + connectors for the
> daisy-chain, opto-isolators / level shifters on the 5 V TTL inputs, FET/buffer drivers on
> the outputs, and the photodiode front-end (Teensy or ADC). Until then, wire it discretely
> per the tables above; the pin map is chosen to survive the transition unchanged.

---

## Software prerequisites

- **I²C enabled**: `raspi-config` → Interface Options → I²C. Verify with `i2cdetect -y 1`
  → both `5a` (MPR121) and `36` (AS5600) present.
- **GPIO library** (reward, photodiode — the only header-touching devices now):
  - **Pi 4B (`main` branch — the leader today)** — `pigpio` with the `pigpiod` daemon running
    (`sudo pigpiod` / the `pigpiod` service).
  - **Pi 5 (`dev-pi5` branch)** — `lgpio`, opening **`gpiochip0`** (the 40-pin
    header). No daemon; works on the Pi 4 too. Override the chip in the rig YAML with
    `gpiochip:` if an early Pi 5 image enumerates the header as `gpiochip4`; confirm with
    `gpiodetect`. The pin map is identical. (Background: `PI5_LEADER_FEASIBILITY.md` in the
    local-only `docs/assets/` stash.)
- **Teensy firmware**: flash `teensy/photodiode_sync/photodiode_sync.ino` with
  Arduino + Teensyduino (`PD_PIN = A1`, `OUT_PIN = 16`, `DEBUG = 0`).

---

## Settings that depend on this wiring

- `devices.reward.calibration.main` (`[[10, 4]]` → 10 ms pulse ≈ 4 µL); see
  [`reward_calibration.py`](../devices/reward_calibration.py).
- `devices.photodiode.pulse_every_n_frames` (5) must match the sync-patch cadence on
  the follower (`stimulus.photodiode_sync_every_n` in the task YAML).
- `devices.photodiode.sync_corner` / `sync_size_px` / `sync_brightness` set the on-screen
  sync patch that **the follower** draws (the photodiode is taped over it) — they ride into
  the follower's display config, they are not the leader's GPIO settings.
- `devices.encoder.wheel_diameter_cm` (14.4) and `sample_hz` (500) set the wheel angle →
  distance/speed conversion and the running-wheel logging rate.

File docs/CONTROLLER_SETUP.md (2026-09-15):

# Controller Setup — new machine

How to bring up the VRFarm **controller** (the Mac/Linux box running `controller/app.py`)
on a fresh machine and get it talking to the two rig Pis. Linux/Ubuntu is
the reference here; macOS is the same minus the netplan step, Windows notes at the bottom.

The controller reaches the Pis entirely over the network — HTTP (REST) + UDP for the
experiment loop, plus SSH/SCP for the setup UI's deploy/calibrate actions. There is nothing
machine-specific baked into the rig config; any host on the rig subnet can drive the rig.

---

## 0. What the controller needs

| | |
|---|---|
| A wired NIC on the **experiment switch** | static IP on `192.168.10.0/24` |
| A second NIC (WiFi) | internet + NTP; stays the default route |
| Python env `vrfarm` | flask requests scipy matplotlib numpy h5py pyyaml |
| Passwordless SSH to both Pis | only for the setup UI (deploy/warp/calibrate) |

The Pis are static: **Leader `192.168.10.101`**, **Follower `192.168.10.102`**,
both user `vruser`.

---

## 1. Network — static IP on the wired NIC

The address is not baked into the Pis — the Leader learns it from the source of the first UDP
command and replies there, and the event listener binds `0.0.0.0:5571` — but **`controller_ip` in
`controller/configs/controller.yaml` must match it**: the Network tab derives new rig IP pairs from
its /24 (`controller/network.py`) and the Setup tab builds the geometry-callback URL from it
(`controller/setup.py`). `192.168.10.1` is the default. Stay clear of the rest of the address
plan: **`.101`–`.250` are rig IP pairs** (the Network tab hands them out) and **`.251`–`.254` are
infrastructure** (the switch's web UI is `.254`).

> Before claiming `.1`, make sure no other machine (an old Mac/Windows controller) is holding
> it on the switch, or duplicate-address detection will reject it. Pick a free `.x` otherwise.

### Ubuntu (netplan + NetworkManager)

If `nmcli connection show` lists your wired connection as `netplan-<iface>`, netplan owns it —
configure it in netplan (an `nmcli` edit can be overwritten on the next apply).

First, if NetworkManager has auto-created a DHCP profile bound to the rig NIC (`Wired connection N`
in `nmcli connection show`, `connection.interface-name` = your NIC), delete it **before the NIC gets
a link**, or NM starts DHCP on it. NM then remembers the MAC and won't recreate it:

```bash
sudo nmcli connection delete "Wired connection 1"    # only the one bound to your rig NIC
```

Then add a **separate, additive** drop-in:

```bash
sudo tee /etc/netplan/99-vrfarm-rig.yaml >/dev/null <<'EOF'
network:
  version: 2
  renderer: NetworkManager
  ethernets:
    rig0:                      # just an id — the match below is what binds the card
      match:
        macaddress: "c4:62:37:0c:16:68"   # <-- your rig NIC's MAC (ip -br link)
      dhcp4: false
      dhcp6: false
      addresses:
        - 192.168.10.1/24
      # no gateway4 / routes on purpose -> this NIC never becomes the default route;
      # WiFi stays the internet path
EOF
sudo chmod 600 /etc/netplan/99-vrfarm-rig.yaml
```

Apply it **without** `netplan apply` or `netplan try`. Both restart NetworkManager, disconnect WiFi
and flush addresses — on fystyk WiFi dropped for ~4.5 s and rejoined a *different* SSID — and a
reverted `try` still leaves the edited YAML on disk. This rewrites only the generated files and
never touches WiFi:

```bash
sudo netplan generate
sudo nmcli connection reload
sudo nmcli connection up netplan-rig0
```

**Match the card by MAC, never by interface name.** `enpXsY` follows the card's PCI slot, so it
changes with no edit on your side: on fystyk the 10G card came back as `enp4s0` after a reboot (it
had been `enp6s0`), the name-keyed stanza matched nothing, and every rig went unreachable while the
card and its 10G link were perfectly healthy. The signature is `ip -br addr` showing the rig NIC up
with no address. A `set-name:` is not the fix — netplan then binds the NM profile to that name and
the rename only lands at the next boot, so the apply fails meanwhile.

**Moving the rig link to another NIC** (what fystyk did when a 10G card replaced the onboard port):
unplug the old NIC's cable first so the two can never both hold `.1`, back up, point `match:` at the
new card's MAC, and review the *merged* config before applying — the installer's own netplan file
may define the old NIC as well:

```bash
sudo cp -a /etc/netplan /root/netplan-backup
ip -br link                     # the new card's MAC
sudo sed -i 's/<old-mac>/<new-mac>/' /etc/netplan/99-vrfarm-rig.yaml
sudo netplan get ethernets      # the rig stanza carries the address; the old NIC must have none
```

Keep the `ethernets` argument: a bare `netplan get` also prints the WiFi passwords. If the old NIC
still appears with only a `match:`/`set-name:` (installer-written, no address), leave it — that
profile stops NM auto-creating a DHCP connection for the unused port. Roll back with
`sudo cp -a /root/netplan-backup/. /etc/netplan/` followed by the three apply commands above.

**fystyk's rig NIC** is an Intel 82599ES 10G SFP+ card (Argus ST-7211), in-kernel `ixgbe` — no
vendor driver pack — with a passive DAC into the switch's SFP+ port. Any DAC is accepted; third-party
*optics* need `options ixgbe allow_unsupported_sfp=1`. A 10G controller link matters with several
rigs: the Data tab's parallel syncs would otherwise saturate the one link every running rig's UDP
also uses.

### macOS

System Settings -> Network -> the Ethernet/adapter -> Details -> TCP/IP -> Configure IPv4
**Manually**, IP `192.168.10.1`, mask `255.255.255.0`, **router blank**.

### Verify (any OS)

```bash
ip -4 addr show <iface>       # expect inet 192.168.10.1/24   (macOS: ifconfig)
ip route                      # default route must be via WiFi/internet, NOT the wired NIC
ping -c3 192.168.10.101       # leader
ping -c3 192.168.10.102       # follower
```

### Firewall

The Leader pushes UDP events to the controller on **5571** — that inbound port must be open.
- Linux: `ufw` is usually inactive (nothing to do). If active:
  `sudo ufw allow from 192.168.10.0/24 to any port 5571 proto udp`
- macOS: the application-layer firewall prompts to allow `python`; allow it.

---

## 2. Passwordless SSH to the Pis

The **Setup** tab needs this (Install, push warp maps, reboot, calibration hand-off) and so does the
**Data** tab, which syncs, purges and powers off over SSH only. Running an experiment uses no SSH.
Each new controller must add **its own** key to the Pis — they only trust the keys already
installed.

```bash
# 1. Reuse an existing key or make one (no passphrase = simplest for the app's non-interactive ssh)
ls ~/.ssh/id_ed25519.pub || ssh-keygen -t ed25519

# 2. Install it on each Pi (prompts for the vruser password once; sets perms + known_hosts)
ssh-copy-id vruser@192.168.10.101
ssh-copy-id vruser@192.168.10.102

# 3. Verify — both print "ok" with NO password prompt
ssh vruser@192.168.10.101 "echo ok"
ssh vruser@192.168.10.102 "echo ok"
```

Notes:
- the SSH helpers in `controller/ssh.py` run non-interactively (no TTY), so the key must log in
  without a prompt **and** each Pi's host key must already be in `~/.ssh/known_hosts` — the
  interactive `ssh` in step 3 seeds it.
- If your key has a **passphrase**: on a Linux/macOS desktop the login keyring's ssh-agent
  auto-unlocks it per session, so the controller's `ssh` calls still work. If not, either use a
  passphrase-less key for the Pis or `ssh-add` the key before launching `controller/app.py`.

---

## 3. Python environment

```bash
conda create -n vrfarm python=3.11 -y
conda activate vrfarm
pip install flask requests scipy matplotlib numpy h5py pyyaml
```

Controller-only deps — `picamera2`/`lgpio` live on the Pis, not here. The setup UI builds
the warp map with `sys.executable`, so it uses whatever `python` is running the UI (this env).

---

## 3b. Data directory (machine-specific — NOT in the rig yaml)

Synced session data and the subject database live in a **controller-local** root, the same
tree for every rig, resolved at runtime:

0. `data_root` in `controller.yaml` — the Data tab's **Data root** field / Browse… writes it, else
1. `$VRFARM_DATA_DIR` if set (e.g. point it at a big SSD mount), else
2. `~/VRFarm/data` — the same convention on every OS
   (`/Users/<user>` on macOS, `/home/<user>` on Linux, `C:\Users\<user>` on Windows).

Nothing to configure for a default setup — the directory is created on first sync.
To use a dedicated drive, export the variable before launching the UI (and persist it in
`~/.bashrc` / `~/.zshrc`):

```bash
export VRFARM_DATA_DIR=/mnt/ssd/vrfarm-data
```

The rig yaml deliberately has **no** controller path (`data.mac_dir` was removed: a
machine-specific absolute path in a shared config broke every other controller — the
original Linux symptom was `Transfer failed: cannot create /Users/... permission denied`).
The yaml's `data.leader_dir` / `data.video_dir` are Pi-side paths and stay.
The Data tab's **Data root** field is the normal way to point at a drive; it is saved in
`controller.yaml` and wins over the environment variable.

---

## 4. Launch and validate

The Data tab copies with `rsync`, which must be a real rsync (3.1 or newer). With `rsync_path: null`
in `controller.yaml` the controller looks **only in the `vrfarm` env** (`sys.prefix/bin/rsync`, no
PATH fallback — `controller/settings.py`), and a fresh env has none. Either install it there:

```bash
conda install -n vrfarm -c conda-forge rsync
```

or, **on Linux**, point at the system one, which is real rsync (fystyk: 3.4.1):

```yaml
rsync_path: /usr/bin/rsync          # controller/configs/controller.yaml
```

On **macOS** only the first option works: `/usr/bin/rsync` there is Apple's openrsync, which the Data
tab rejects. The Data tab shows a banner naming whichever problem it finds.

```bash
conda activate vrfarm
python controller/app.py  # -> http://localhost:5000 (Network / Setup / Experiment / Data)
```

1. **Network** tab -> **Check all**: every Pi should show a green dot. **Setup** tab -> Load rig:
   the page checks the Pis again; then **Initialize** to bring the devices up.
2. **Deploy** to push current engine/device code to the Pis.
3. Experiment UI -> **Load Rig** -> **Load Experiment** -> **Deploy** -> run a short
   **5-trial** session; live events appearing in the dashboard proves inbound UDP 5571 and
   the Leader's reply-to-sender work.

Both UIs are walked through with screenshots in [SETUP_UI.md](SETUP_UI.md) and
[EXPERIMENT_UI.md](EXPERIMENT_UI.md). To validate the controller with no rig attached, run
`python tools/mock_pi.py` and use the `demo` rig.

---

## Ports reference

| Port | Proto | Direction | Purpose |
|---|---|---|---|
| 5080 | TCP | controller -> both Pis | REST API (deploy, config, start/stop, data, camera) |
| 5572 | UDP | controller -> Leader | START/STOP/REWARD (first packet teaches the Leader the return address) |
| 5571 | UDP | Leader -> controller **(inbound)** | trial/lick/reward/stim/sync events |
| 5575 | UDP | Leader -> Follower | SHOW/QUIT (Pi-to-Pi; not the controller) |
| 22 | TCP | controller -> both Pis | SSH/SCP: Setup tab (Install, calibration) and Data tab (rsync, purge, poweroff) |
| 5000 | TCP | localhost | the one controller UI (Network / Setup / Experiment / Data) |
| 80 | TCP | controller -> switch | Zyxel XGS1210-12 web UI at `192.168.10.254` |

---

## OS notes

- **macOS**: port 5000 clashes with AirPlay Receiver — disable it in System Settings ->
  General -> AirDrop & Handoff, or the experiment UI won't bind.
- **Windows**: viable but needs the extra fixes on the `windows-port` branch (UDP
  `SIO_UDP_CONNRESET` guard, UTF-8 file encoding, LF `.gitattributes`, a PowerShell folder
  picker) plus a Windows-Firewall inbound rule for UDP 5571 on **all** profiles. See that
  branch's commits if returning to Windows.

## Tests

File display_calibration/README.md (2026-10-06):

# Display / screen calibration

Standalone tools for calibrating the parabolic projection screen, plus the warp-map
generator the experiment uses. The single source of truth is **`rig_geometry.yaml`**
(see [geometry_params.md](geometry_params.md) for every field). The Rig Setup UI loads
the same file into editable boxes; `rigs/<rig>.yaml` points a rig at its file via
`display.geometry_file`.

```
<rig>/geometry/rig_geometry_<stamp>.yaml ──► compute_warp_map.py ──► <rig>/warp_map.npz
        ▲  ▲                                      ▲
        │  └── Setup tab: edit boxes, Save Rig   └── <rig>/intensity/intensity_cal_*.yaml (the rig's, via Apply)
        └───── calib_geo.py: Save on the Pi, sent back as a new dated file
```

## Where the files live

```
display_calibration/                          scripts, shared by every rig
├── _template/                                 one template per file kind; geometry/ seeds new rigs
└── <rig>/                                    one folder per rig (created on first use)
    ├── geometry/rig_geometry_<YYYYmmdd_HHMM>.yaml     one file per calibration, never edited
    ├── intensity/
    │   ├── intensity_cal_<stamp>.yaml                 measured: light vs drive at 2+ chosen
    │   │                                              azimuths (3+ recommended), one altitude
    │   ├── intensity_cal_<geostamp>_theoretical.yaml  mock from the geometry (the default)
    │   └── intensity_cal_none.yaml                    mock: no correction
    └── warp_map.npz                                   generated; carries the light model (int_*)
```

The rig YAML's `devices.display.geometry_file` names the geometry the rig uses. Dated files are
records: **Save Rig** with edited values writes a *new* `rig_geometry_<now>.yaml` and points the rig
at it; the Geometry Cal tool's Save also lands as a new dated file. None of these files are in git
(only the `_template/` ones are): they live on the controller, so back them up.
On the Pis nothing changed: `~/rig/calibration/` holds `warp_map.npz` + `rig_geometry.yaml`.

**Intensity calibration.** One file per measurement (format: `_template/intensity/intensity_cal_template.yaml`):
one column per azimuth you choose = light vs drive 1.0..0.0 there (two minimum, three or more out
to the screen edge recommended), all at one altitude. `shared/intensity_model.py` builds a
per-level light table from it (for each drive level, light interpolated across the columns'
azimuths — no response shape is shared between azimuths) that the warp carries to the renderer,
the Leader and the controller, so the background is uniform in light, Bg is a brightness (0..1 of
the uniform range) and contrast is contrast of light. The rig uses the file named by `devices.display.intensity_calibration`
(Setup → INTENSITY → Apply). Protocol: `docs/CALIBRATION_PROTOCOL.md`, Part 2.

## Files

| File | What it is |
|---|---|
| `<rig>/geometry/rig_geometry_<stamp>.yaml` | The geometry params (screen, projector, mouse, luminance), one dated file per calibration. |
| `calib_geo.py` | **Live geometry tool** — slider panel on your Mac, isolines drawn on the projector, Save overwrites `rig_geometry.yaml`. |
| `compute_warp_map.py` | Builds `warp_map.npz` from `rig_geometry.yaml`. Run by the setup UI's *Generate Warp*. |
| `panel_grid.py` | Numbered panel grid (raw, no warp) for eyeballing coverage. |
| `validate_calibration_pygame.py` | Renders the finished warp grid on the projector to check it. |
| `cal_start.sh` / `cal_stop.sh` | Start/stop a tool on mozzarella (survives the SSH session). |
| `intensity_cal.py` | Intensity calibration files: save (fit-validated), theoretical/none mocks, list, load. |
| `validate_calibration.py` | Legacy offline validation helper (PsychoPy; does not run on the follower). |

## The two ways to set geometry

**1. Type the numbers (Rig Setup UI).** Load the rig → the Display device card shows
editable boxes for screen / projector / mouse params (incl. `horizontal_stretch` /
`vertical_stretch`). Change any value and hit **Save Rig** — that writes both the rig
config (`rigs/<rig>.yaml`) and the geometry (`rig_geometry.yaml`) in one click. Then
**Generate Warp** rebuilds `warp_map.npz` and pushes it (and `rig_geometry.yaml`) to the
Pis. Toggle **Apply warp** to switch the experiment between warped / unwarped rendering.

**2. Tune it live (calib_geo.py).** Needs the projector, so it runs on mozzarella. It
draws azimuth/altitude isolines *through* the screen+projector geometry, so the screen
**curvature** (`parabola_B`) is a live slider — the thing you can only set by eye.

```bash
# on mozzarella (projector X must be up):
bash ~/rig/calibration/cal_start.sh geo      # geometry sliders, web UI on :5091
#   then open http://192.168.10.102:5091 on your Mac
bash ~/rig/calibration/cal_start.sh panel    # numbered panel grid
bash ~/rig/calibration/cal_start.sh warp     # validate the finished warp grid
bash ~/rig/calibration/cal_stop.sh           # stop whatever is running
```

Tune **`parabola_B`** until the cyan horizontal lines are straight/level on the curved
screen, then click **Save** — that overwrites `rig_geometry.yaml` *next to the script on
the Pi*.

> The `flip_h/flip_v/offset_x/offset_y` sliders only orient the live **preview** to match
> the physical projector; the experiment render path ignores them, so they are **not**
> written into `rig_geometry.yaml` (they persist to `.calib_preview.json` instead).

## Mac ↔ Pi sync

The controller's `<rig>/geometry/` is the master copy.

- **Controller → Pi:** *Generate Warp* copies `<rig>/warp_map.npz` **and** the selected geometry
  file (as `rig_geometry.yaml`) to each Pi's `~/rig/calibration/`.
- **Pi → controller:** calib_geo's Save posts the file to the Setup tab, which stores it as a new
  `<rig>/geometry/rig_geometry_<now>.yaml`; refresh the geometry list, select it, **Save Rig**, and
  **Generate Warp** to bake it in.

First-time only: deploy the tool scripts to the Pi if they aren't there yet —
`scp calib_geo.py panel_grid.py validate_calibration_pygame.py cal_start.sh cal_stop.sh
vruser@192.168.10.102:~/rig/calibration/`.

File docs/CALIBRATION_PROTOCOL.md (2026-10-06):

# Rig Calibration Protocol

**Rig:** `rigs/cheddar.yaml` (listed as `cheddar` in the UI dropdowns) — display on the Follower (RPi4 + DLP **rear-projector**) + parabolic screen; reward valve on the Leader
**Last updated:** 2026-08-03
**Files:** `display_calibration/` in the repo (on the controller); `~/rig/calibration/` on the follower

---

## Overview

Calibration has three independent parts that can be done separately:

| Part | What it does | When to redo |
|---|---|---|
| **Geometric warp** | Maps visual angles (azimuth, altitude) to projector pixels | If projector or screen moves |
| **Luminance (intensity) correction** | Equalizes delivered luminance across screen locations | If bulb ages, screen is replaced, or geometry changes |
| **Reward valve** | Maps pulse duration (ms) to dispensed volume (µL) | If the valve, tubing, or reservoir head changes |

The geometric warp and the luminance correction are both stored in `warp_map.npz` and referenced by every experiment. The reward calibration is a small ms→µL table stored per-rig in the rig YAML.

Everything is driven from the controller's **Setup tab** (`controller/setup.py`, localhost:5000; since the
multi-rig controller each rig's calibration files live in `display_calibration/<rig>/` — see `docs/MULTI_RIG.md`): the display card (RENDERING / TESTS / **CALIBRATION** / GEOMETRY sub-sections) and the reward card. The command-line tools still exist for manual runs.

> **Rear projection.** The projector sits **behind** the screen; the image is seen from the front. The warp therefore mirrors the frame — `flip_h` / `flip_v` in the geometry `calibration:` block. The projector model (`compute_warp_map.build_projector`) places the lens *behind* the screen looking back toward the eye; the flip must be **re-registered** (Part 1, Step 3) whenever the projector or its model changes.

---

## Part 1 — Geometric Warp Map

### What it does

The parabolic screen is curved, so a flat image from the projector produces distorted positions on the screen. The warp map computes, for any target visual angle (azimuth, altitude) as seen from the mouse eye, exactly which projector pixel to illuminate. This is computed analytically from the screen's parabola equation (`y = A − B·x²`) and the projector's rear-projection throw geometry, then mirrored to display space (`display_calibration/compute_warp_map.py`).

### Where it runs

The warp is **ray-traced on the controller** (Mac/Ubuntu, the miniforge `vrfarm` env has numpy/scipy/yaml/matplotlib) and the resulting `warp_map.npz` is deployed to both Pis — the Leader generates stimuli from it (`shared/stim_generator.py`), the Follower renders through it (`devices/display.py`). The *geometry* itself is calibrated interactively **on the follower** with the projector running.

### Prerequisites

- Projector is mounted in its final rear position and warmed up
- Screen and mouse platform are in their final positions
- `displayd` is running on the follower and healthy (`curl :5581/status` → `RENDERER_UP`).
  There is no X server: `cal_start.sh` asks displayd to stand aside (POST `:5581/standby`)
  and `cal_stop.sh` gives the display back (POST `/resume`). calib_geo runs on kmsdrm under
  the **system** `/usr/bin/python3` — the conda env's SDL has no kmsdrm backend.

### Step 1 — Calibrate the geometry (landmark registration)

Geometry is no longer hand-tuned from abstract stretch factors. The **`calib_geo.py`** landmark tool registers the projected grid to physical reality and back-solves the geometry.

In the setup UI, display card → **CALIBRATION → "Calibrate"**. This deploys the calibration tools to the display Pi, has displayd release the display, launches `calib_geo`, and opens its live sliders at `http://<display-pi>:5091` (`controller/setup.py:api_start_calibration`; a `calibration_probe`, if configured, is latched TTL HIGH while calibrating).

Register these landmarks against the physical screen (`display_calibration/calib_geo.py`):

1. **`frame_x` / `frame_y_top` / `frame_y_bottom`** — slide the cyan boundary lines onto where the projector light meets the physical screen edges. The enclosed rectangle is the **usable pixel area**. `frame_x` is a single symmetric left/right inset; top and bottom are independent. These stay tied to the physical top/bottom even with `flip_v` on.
2. **`offset_x` / `offset_y`** — move the green 0° cross (vertical = az 0° meridian, horizontal = alt 0° eye-level line) onto physical straight-ahead. That intersection is the coordinate origin.
3. **`azimuth_height` (cm)** — measure IRL from the horizontal green line to the screen bottom and type it in. With `height_cm` and `parabola_A` it **derives** the altitude range: `altitude_min = atan(−h/A)`, `altitude_max = atan((height−h)/A)`.
4. **`az90_x`** — drag the green ±90° azimuth lines onto the physical 90° marks. The tool **solves** `horizontal_stretch` so the model projects ±90° exactly there, and `vertical_stretch` so the altitude range fills the usable area.
5. **`parabola_B`** — tune only the mid-field curvature against the cyan 30° grid; the ±90° and altitude endpoints stay anchored.

Set **`flip_h` / `flip_v`** to whatever makes the whole image (including text) read correctly on the physical screen — that combination is the projector's rear-projection transform.

**Save** overwrites `rig_geometry.yaml` (the deliverable) with the solved geometry, the derived altitudes, and a `calibration:` block (flip / offset / frame / az90 landmarks). Then **"Stop Calib"**.

> The display card's **SCREEN / VISUAL SPACE / PROJECTOR** rows also expose the geometry numerically (A depth cm, B curve, height cm, throw ratio/cm, H/V stretch, axis elev°, lens offset, lateral offset) with live derived Alt/Az min/max read-outs. Edits there persist to the selected geometry file on **Save Rig** — but the landmark tool is the intended way to *produce* a calibration.

### Step 2 — Regenerate the warp map

In the setup UI, display card → **GEOMETRY**: pick the geometry **File** in the dropdown, then click **"Generate Warp"** / **"Regenerate Warp"** (`controller/setup.py:api_generate_warp`). This ray-traces the selected `rig_geometry.yaml` into `warp_map.npz` **on the controller**, atomically copies the NPZ *and* the geometry to every Pi, and reloads the live display. The light model baked in is the rig's intensity calibration (`devices.display.intensity_calibration`, default: the theoretical mock of the geometry) — see Part 2.

Manual/CLI equivalent (on the controller, in `display_calibration/`):

```bash
conda activate vrfarm
python compute_warp_map.py --validate            # → warp_map.npz + warp_map_validation.png
python compute_warp_map.py --geo <rig>/geometry/rig_geometry_<stamp>.yaml --intensity-cal <rig>/intensity/intensity_cal_<stamp>.yaml --cal-dir <rig>
```

`--validate` writes `warp_map_validation.png` with four panels:
1. **Azimuth map** — grades smoothly from red (−105°) through white (0°) to blue (+105°). No sharp discontinuities.
2. **Altitude map** — smooth gradient (viridis) bottom to top.
3. **Forward map — azimuth/altitude grid** — isolines at ±80° (red), ±40° (orange), 0° (white). Lines should look plausible given the screen shape.
4. **Luminance correction (theoretical)** — smooth *monotone* falloff from 1.0 at center toward the edges (projector-incidence model). This is the fallback; a measured curve replaces it when the mode is `empirical` (Part 2).

The console prints **visible-screen coverage** (% of pixels the warp fills); very low coverage means the geometry is off.

### Step 3 — Visual validation on the projector

Run on the follower with the projector on (`display_calibration/validate_calibration_pygame.py` — pygame, since the follower has no PsychoPy; the old `validate_calibration.py` used PsychoPy and never ran on the follower):

```bash
/usr/bin/python3 validate_calibration_pygame.py \
    --warp ~/rig/calibration/warp_map.npz [--flip-h] [--flip-v]
```

It draws azimuth/altitude isolines (from the inverse `az_map`/`alt_map`/`valid_map` that `display.py` actually renders with), orientation labels, and a large asymmetric "F". Find the `--flip-h`/`--flip-v` combination that makes the **entire image read correctly** on the physical screen — that combination is the projector's transform, and it is what you set as `flip_h`/`flip_v` in Step 1 so stimulus pixels land right. Patterns cycle with SPACE (or `--cycle SECONDS` headless); Q/ESC or SIGTERM to quit.

### `rig_geometry.yaml` — the calib_geo deliverable

```yaml
screen:
  parabola_A: 13         # vertex depth (cm) — eye→screen distance at 0° azimuth
  parabola_B: 0.055      # curvature, y = A − B·x²   (mid-field landmark)
  azimuth_height: 7.5    # cm from the alt-0 line to the screen bottom (measured IRL)
  height_cm: 20          # physical screen height
  altitude_min_deg: -29.98   # DERIVED from azimuth_height/A/height_cm
  altitude_max_deg: 43.88    # DERIVED
projector:
  resolution: [1920, 1080]
  throw_ratio: 1.2
  throw_distance_cm: 48
  optical_axis_elevation_deg: -9.0     # beam elevation (negative = up)
  horizontal_stretch: 0.658            # SOLVED from az90_x landmark
  vertical_stretch: 1.140              # SOLVED so altitude fills the usable area
  lens_offset_vertical: 1              # 0=center … 1=100% upward shift
  lateral_offset_cm: 0
calibration:                # landmark block — set by calib_geo, do NOT hand-edit
  flip_h: false
  flip_v: true
  offset_x: 0
  offset_y: -405
  frame_x: 207
  frame_y_top: 4
  frame_y_bottom: 0
  az90_x: 1628
```

> `horizontal_stretch` / `vertical_stretch` are **solved** from the landmarks, not typed. `altitude_min_deg` / `altitude_max_deg` are **derived** from `azimuth_height`, `parabola_A`, `height_cm`. Older files carried an `azimuth_max_deg` — `calib_geo` drops it (the filled azimuth range is now derived from where the frame edges land on the parabola).

---

## Part 2 — Intensity Calibration (light model)

### What it does

The projector delivers less light to oblique screen positions, its light is not proportional to
its drive level, and a drive of 0 still leaves a black floor (DMD leakage + stray light). One
intensity calibration measures all three, and a light model built from it
(`shared/intensity_model.py`) lets every part of the system work in **light** rather than drive:

- the background is uniform in light across the screen,
- **Bg / background_gray is a brightness**: 0..1 of the uniform range (0 = the darkest light
  every azimuth can show, 1 = the brightest),
- contrast is computed on light (Weber, Michelson or normalized), including the floor — on a
  "black" background Weber contrast is finite and large.

The model is baked into `warp_map.npz` (arrays `int_*`) by Generate Warp / Apply and used, from
that one file, by the renderer (per-pixel drive), the Leader (stimulus generation) and the
controller (previews, Correct).

### One file, one altitude

`display_calibration/<rig>/intensity/intensity_cal_<stamp>.yaml`
(format: `display_calibration/_template/intensity/intensity_cal_template.yaml`):

| Part | What you measure |
|---|---|
| Columns — `level_sweeps` | one column per azimuth you choose: light at drive 1.0, 0.9 … 0.1, 0.05, 0.0 there (0.0 = the black floor). Two columns are the minimum; three or more out to the screen edge (e.g. 0°, 40°, 80°) is the useful case, and a column on the other side of centre checks the left/right symmetry the model assumes |

The model is a table, not a formula. Every column is put on the common level grid, and **for each
drive level separately** the light is interpolated linearly across the columns' |az| (readings at
+az and −az are averaged) and held constant beyond the last column. So each level has its own
azimuth curve — the response may differ in shape from the centre to the edge — and the only
assumption between columns is linear interpolation of light. The renderer inverts the table per
pixel: the drive at which that azimuth's curve reaches the target light. The uniform range is
`max L(az, 0) .. min L(az, 1)` over the calibrated azimuths. Azimuth resolution is the number of
columns, so put one near every azimuth the paradigm uses.

**Mocks.** Without a measurement the rig uses a mock in the same format: two levels per column
(drive 0 = 0, drive 1 = the column's gain), no floor. `intensity_cal_<geostamp>_theoretical.yaml`
(one column per azimuth sample of the geometry model, gain = its cos(incidence) — the default,
identical to the old theoretical correction) or `intensity_cal_none.yaml` (flat — brightness is
the drive). Both are written automatically for the current geometry.

### Procedure

1. Load the rig, **Initialize** the display. Projector warmed up (≥ 15 min), room dark, meter
   (Thorlabs PM100D, or any linear meter) on a stand.
2. Display card → **INTENSITY → Measure…**. Set **Alt** (used for the whole calibration),
   **Size** (default 15°, overfills the sensor) and **Unit** (a label, e.g. lux).
3. Columns: the panel opens with columns at 0°, 40° and 80°; edit the azimuth in a header,
   **+ column** for more (−40° to check symmetry, 100° if the paradigm goes there), × to remove.
   Rows are the drive levels 1.0 … 0.0; **+ level** adds one, × removes one (1.0 and 0.0 stay).
4. For each cell press **▶** (the patch lights at that drive, raw, at the column's azimuth) and
   **R** (PM100D) or type the value. R advances to the next empty row of the column.
5. **Save** writes the file and logs a fit report (uniform range, columns, how much the columns'
   normalized response shapes differ, left/right asymmetry). **Save & Apply** also applies it.
6. **Apply** (or pick any file in the **Calibration** dropdown, then Apply) rebuilds
   `warp_map.npz` with that file's light table, deploys it to the Pis, reloads a live display and
   records the choice in the rig YAML (`devices.display.intensity_calibration`, saved at once).

### What good output looks like

- Column tops (drive 1.0) descend toward the edges; a ±az pair agrees within a few percent.
- Every column rises monotonically from its floor to its drive-1 reading (a dip is a meter or
  typing slip — the fit flattens it, but fix the number).
- The shape spread in the report says how non-separable the screen is: small (a few %) means one
  response curve would have fit everywhere; large means the per-level curves are doing real work,
  and the columns had better sit near the azimuths you use.
- Check after Apply: TESTS → Blank at a mid brightness and read the meter at a few azimuths,
  between the columns too; the light should match within a few percent.

### Gray scale & contrast metric

- **Bg / `stimulus.background_gray` = brightness**, 0..1 of the uniform range (`L = Lo + b·(Hi − Lo)`).
  With the none mock it is the plain drive; with the theoretical mock it is the old corrected drive.
- **Contrast** (`stimulus.contrast.values`, typed in percent in the UI, stored as fractions) is
  defined on light, in the rig's metric (display card RENDERING → Contrast metric):
  Weber `(Ls − Lb)/Lb`, Michelson `(Ls − Lb)/(Ls + Lb)`, normalized `(Ls − Lb)/(Hi − Lb)` (fraction of
  the uniform headroom). Weber/Michelson on a background without light (a mock at brightness 0)
  fall back to normalized.
- A stimulus may be brighter than the uniform ceiling where the screen can deliver it; past
  drive 1 a pixel clips. **Correct** clamps to what every session azimuth can show.

---

## Part 3 — Reward (Valve) Calibration

The reward valve (`devices/reward.py`, on the Leader) maps **pulse duration (ms) → dispensed volume (µL)** via a small calibration table. The old automated routine (`devices/reward_calibration.py`) is **deprecated**; the editable table in the setup UI is the default workflow.

### Where it lives

Setup UI → **reward card** (see [SETUP_UI.md](SETUP_UI.md#reward-valve)). The calibration is an editable **ms / µL** table (per-pulse volume), stored in the rig YAML at `rig.devices.reward.calibration.main = [[ms, µL], …]`.

### Procedure

1. Init the reward device (Load Rig / Init Devices) so the **Deliver** button is enabled.
2. For each pulse duration you want to characterize, deliver a **known number of pulses** at that duration (the card's **Deliver** control fires the pulse `×N` at an `every … s` interval; count/train uses `pulse_gap_ms` between pulses).
3. Collect and **weigh** the dispensed water (1 µL ≈ 1 mg), divide by the pulse count → **µL per pulse**.
4. Enter the `ms` and per-pulse `µL` into a table row (**+ Row** / **− Row** to add/remove), then **"Save Calibration"** — this writes the table into the rig config (`applyCalibration` → Save Rig).

### How the engine uses it (`devices/reward.py`)

- **One calibration row** → proportional scaling (e.g. `[100, 4]` → 25 ms/µL).
- **Two or more rows** → linear interpolation with extrapolation (`load_calibration`, scipy `interp1d`).
- **Volume mode** (`amount_mode: volume`) — one pulse, its duration interpolated for `amount_ul`.
- **Count mode** (`amount_mode: count`) — `amount_count` repeats of the **base pulse** (the **first** calibration row), separated by `pulse_gap_ms`.

Aim for ≥3–4 well-spaced rows spanning the durations you actually deliver, so the interpolation is accurate over the working range.

---

## Calibration File Reference

```
display_calibration/                 (on the controller; deployed to ~/rig/calibration/ on the Pis)
├── rig_geometry.yaml               # Physical geometry + landmark block — the calib_geo deliverable
├── calib_geo.py                    # Interactive landmark geometry calibrator (sliders on :5091)
├── cal_start.sh / cal_stop.sh      # Launch/stop the on-Pi calibration tool
├── panel_grid.py                   # Projector panel grid helper (deployed with the tools)
├── compute_warp_map.py             # Ray-traces rig_geometry.yaml → warp_map.npz
├── validate_calibration_pygame.py  # On-projector warp validator (pygame; --flip-h/--flip-v)
├── validate_calibration.py         # Legacy PsychoPy validator (does not run on the follower)
├── intensity_cal.py                # intensity calibration files: save / mocks / list / load
│
├── warp_map.npz                    # Generated — used by all experiments
│   contains:
│     az_map           (H×W)        Azimuth in degrees for each pixel
│     alt_map          (H×W)        Altitude in degrees for each pixel
│     valid_map        (H×W bool)   True where pixel hits screen
│     px_from_az       (Nalt×Naz)   Pixel X for each (az, alt)
│     py_from_az       (Nalt×Naz)   Pixel Y for each (az, alt)
│     az_samples       (Naz,)       Azimuth sample points
│     alt_samples      (Nalt,)      Altitude sample points
│     lum_az, lum_gain_theoretical  Geometry gain (diagnostics/plots only)
│     int_*                         The light model (shared/intensity_model.py): floor F,
│                                   max light M, inverse responses, uniform range lo/hi,
│                                   calibration name — used by renderer, Leader, controller
│
└── warp_map_validation.png         # Last --validate plot
```

Since 2026-09-29 the data files are per rig — `display_calibration/<rig>/geometry/`,
`<rig>/intensity/` and `<rig>/warp_map.npz`; the tree above lists the scripts and the warp map's
contents. Layout and naming: [display_calibration/README.md](../display_calibration/README.md#where-the-files-live).

Reward calibration is **not** a file here — it lives in the rig YAML under `devices.reward.calibration`.

---

## When to Recalibrate

| Event | Geometric warp | Luminance | Reward |
|---|---|---|---|
| Projector moved or refocused | ✓ redo | ✓ redo | — |
| Screen moved or replaced | ✓ redo | ✓ redo | — |
| Projector bulb replaced | — | ✓ redo | — |
| Mouse platform height changed | ✓ redo | — | — |
| Valve / tubing / reservoir changed | — | — | ✓ redo |
| Routine check (every ~3 months) | — | ✓ spot check | ✓ spot check |

---

## Quick Reference — Command Cheat Sheet

```bash
# ── Geometry + warp: PREFERRED path is the setup UI ────────────────────────────
#   Display card → CALIBRATION → "Calibrate"  (landmark tool, sliders on :5091)
#   Display card → GEOMETRY   → "Regenerate Warp"  (builds warp_map.npz on the
#                                                   controller + deploys to the Pis)

# Manual warp build (on the controller, in display_calibration/, vrfarm env):
python compute_warp_map.py --validate                       # + validation plot
python compute_warp_map.py --geo <rig>/geometry/rig_geometry_<stamp>.yaml --intensity-cal <rig>/intensity/intensity_cal_<stamp>.yaml --cal-dir <rig>

# On-projector visual validation (on the follower, projector X up):
/usr/bin/python3 validate_calibration_pygame.py \
    --warp ~/rig/calibration/warp_map.npz [--flip-h] [--flip-v]

# ── Intensity: setup UI → Display card → INTENSITY → Measure… / Calibration + Apply
#   (Apply = compute_warp_map.py --intensity-cal <file> + deploy; no --intensity-cal = theoretical mock)

# ── Reward valve: setup UI → reward card → editable ms/µL table → "Save Calibration"
```

---

## Troubleshooting

**Warp coverage is very low (<50% of pixels):**
The projector geometry is off. Recheck `throw_distance_cm` and `optical_axis_elevation_deg`, and confirm the landmark frame in `calib_geo` sits on the real screen edges. Run `--validate` and check the azimuth map — it should cover most of the frame.

**Azimuth lines in validation look wrong:**
The parabola parameters may be off. Re-measure `parabola_A` (eye→screen distance at 0° azimuth) and re-tune `parabola_B` against the mid-field 30° grid in `calib_geo`.

**Whole image / text reads mirrored on the physical screen:**
Wrong flip. In `validate_calibration_pygame.py` find the `--flip-h`/`--flip-v` combination that makes the "F" and labels read correctly, then set `flip_h`/`flip_v` to match in `calib_geo` and Regenerate Warp (rear projection needs the mirror baked in).

**Luminance correction fit looks noisy:**
One or more meter readings were bad. Re-measure the outlier azimuths (in the intensity-cal panel, click that azimuth's **Read** again, or type a corrected value). The gain should be a smooth curve decreasing from 1.0 at center.

**Contrast patches still look uneven after correction:**
The meter reading may have included ambient light, or the patch didn't overfill the sensor. Turn room lights fully off, increase the patch **size**, and re-measure. Confirm the active mode is **`empirical`** (setup-UI status line), not `theoretical`/`none`.

**Measure… / R (read) does nothing or errors:**
The display must be **Initialized** first (the patch is shown through the live renderer). For automated reads the PM100D must be USB-connected to the controller with `pyvisa`/`ThorlabsPM100` installed — otherwise the panel still works with **manual entry** (type the meter's displayed value).

**Reward volume is off / drifts:**
Re-weigh at a few durations and update the ms/µL table. Use ≥2 rows so the engine interpolates instead of proportionally scaling from a single point, and make sure the **first** row is the base pulse you want count-mode rewards to repeat.

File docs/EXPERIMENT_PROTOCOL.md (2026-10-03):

# Experiment Setup and Running Protocol

**Rig:** Leader Pi + Follower Pi + Controller/Ubuntu (UI)
**Last updated:** 2026-08-03

---

## Overview

```
Controller (controller/app.py Flask, localhost:5000)
  ↔ REST API (HTTP, port 5080) — deploy, config, start/stop, camera
  ↔ SSH — install, calibration hand-off, and the Data tab (rsync sync, purge, power off)
  ← UDP :5571 — events from Leader (trial, lick, reward, stim, sync)
  → UDP :5572 — commands to Leader (START, STOP, REWARD)

Leader (engine/leader.py)
  - Imperative trial loop + all GPIO devices (lick, reward, camera, photodiode)
  → UDP :5575 — display commands to Follower

Follower (displayd)
  - KMS daemon; renderer child is sole DRM master, draws from the pre-generated stim NPZ
  → UDP :5573 — stim_onset / hb_flash acks and display_health back to the Leader
```

Ports are set in the rig config (`rigs/cheddar.yaml`, `network:` block). Each trial
runs the imperative loop in `engine/leader.py`:
**ITI → pre-stim → stim onset → response delay → response window → post-stim → outcome.**
All timing synchronized via NTP (chrony). Data is saved locally on the Leader Pi and
transferred to the controller after the session ends.

---

## One-Time Setup (do once per rig)

### 1. NTP clock synchronization

All machines must share a common clock.

**On each Pi** (sync to internet NTP):
```bash
sudo apt install chrony -y
chronyc tracking
# "System time" should be <1ms
```

### 2. Passwordless SSH from controller to Pis

Required for initial Pi setup. After that, the REST API is used.

```bash
ssh-keygen -t ed25519   # if you don't have a key yet
ssh-copy-id vruser@192.168.10.101   # leader
ssh-copy-id vruser@192.168.10.102   # follower

# Test:
ssh vruser@192.168.10.101 echo "leader OK"
ssh vruser@192.168.10.102 echo "follower OK"
```

### 3. Install dependencies

**Controller** (`conda activate vrfarm`):
```bash
pip install flask requests scipy matplotlib numpy h5py pyyaml
```

**Leader** (`conda activate rig`):
```bash
pip install flask pyyaml numpy scipy h5py smbus2
```
Optional: `picamera2` (camera, enable in rig config).

**Follower** (`conda activate rig`):
```bash
pip install flask pyyaml numpy pygame
```

Both Pis run Debian trixie. The `rig` conda env's Python **must match the system
Python** (3.13) — the camera and GPIO bindings are apt-built for the system Python and
symlinked into the env, so a version mismatch breaks `import picamera2` / `import lgpio`.

GPIO is **lgpio**, which talks to `/dev/gpiochip*` directly: there is **no daemon**, and
nothing to start before a session. It works on both the Pi 4 (BCM) and the Pi 5 (RP1);
`pigpio`/`pigpiod` are retired and do not work on the Pi 5 at all. `pip install lgpio`
builds from source and needs `swig`, so Install uses `sudo apt install python3-lgpio` plus
a symlink into the env — the same pattern as the camera bindings. See
[INITIAL_SETUP_REFERENCE.md](INITIAL_SETUP_REFERENCE.md) for the details.

### 4. Deploy code and install systemd service

Use the rig setup UI:
```bash
conda activate vrfarm
python controller/app.py    # localhost:5000 -> Setup tab
```

Deploy code to each Pi and install the `pi_api/vrfarm.service` systemd unit
(`restart=always`), so the REST API on port 5080 comes up on boot. (Code is also
re-uploaded automatically on every **Deploy** in the experiment UI — see below.)

### 5. SSD for video (Leader, optional)

Camera video is written to the path in the rig config (`data.video_dir`). Point it at a
mounted SSD when recording sustained sessions — the Leader's SD card is too small to hold
video.

```bash
# On the leader:
sudo mkdir -p /media/vruser/ssd
sudo mount /dev/sda1 /media/vruser/ssd
# Auto-mount:
echo "/dev/sda1 /media/vruser/ssd ext4 defaults,nofail 0 2" | sudo tee -a /etc/fstab
```

Then set `data.video_dir` in the rig YAML (`rigs/<rig>.yaml`, e.g. `rigs/cheddar.yaml`) to the
video directory on the SSD, and `data.video_mount` to the mountpoint (`/media/vruser/ssd`): while
it is not mounted, the Data tab won't treat the rig's folders as synced and won't purge them.

### 6. Screen calibration

See `docs/CALIBRATION_PROTOCOL.md`. Produces the geometry warp map and per-pixel
luminance/intensity correction used by `shared/stim_generator.py` when it renders each
stimulus. The rig is **rear-projected** (projector behind the screen, image viewed from
the front), which the geometry model accounts for.

---

## Before Each Session

### 1. Check hardware

- [ ] Ethernet switch powered on, all devices connected
- [ ] Projector on and warmed up (>15 min for stable brightness)
- [ ] Water reservoir filled and tubing primed
- [ ] Lick spout positioned correctly
- [ ] Mouse weighed and recorded
- [ ] Room lights set to experiment condition

### 2. Confirm the Pis are answering

GPIO needs no daemon (lgpio talks to `/dev/gpiochip*` directly), so the only service that
has to be up is the REST API:
```bash
curl http://192.168.10.101:5080/api/status    # leader
curl http://192.168.10.102:5080/api/status    # follower
```
If either is silent: `ssh vruser@<ip> "sudo systemctl status vrfarm"`. **Load Rig** in the
experiment UI does this check for you and initializes every device — a red dot there tells
you the same thing.

---

## Running an Experiment

The Experiment tab drives the workflow left-to-right:
**Load rig → Connect → Load Experiment → (session params) → Deploy → GO → STOP → New session**,
and the Data tab syncs the data off the Leader afterwards.

### Step 1 — Launch the UI

```bash
conda activate vrfarm
cd ~/VRFarm
python controller/app.py    # opens localhost:5000 -> Experiment tab -> Load rig
```

### Step 2 — Load Rig

Select the rig (`cheddar`) from the dropdown and click **Load Rig**. This connects to
both Pis over the REST API **and initializes every enabled device** (display/projector,
lick sensor, reward valve, camera, photodiode) in one step — there is no separate
"Connect" button. Pis show green when they respond; any device that fails to init reports
its error here.

### Step 3 — Load Experiment

Select the task from the dropdown (e.g. `go_nogo_v1`) and click **Load Experiment**.
Tasks are the YAML files in `experiments/`. Loading populates the editable parameter
panels (stimulus / reward / session). You can tweak any parameter inline; **Save** /
**Save As** write it back to a task YAML.

### Step 4 — Set session params

Fill in: **Subject ID**, **Date**, **Session #**, **Notes**. These form the
`session_id = <subject>_<YYYYMMDD>_<NNN>`. (Note: the paradigm **Level** is a *reward*
task parameter edited in the REWARD panel, not a session field.)

### Step 5 — Choose per-device saving

In the Actions row, one checkbox per data-producing device (Camera, Lick, Reward,
Photodiode) — all checked by default. Read at **GO**:
- **Camera unchecked** → livestreams to the preview but writes **no video file**.
- **A behavioral device unchecked** → the Leader skips that device's detailed HDF5
  datasets. Core per-trial outcomes are always written.

### Step 6 — Deploy

Click **Deploy**. This:
1. Uploads the current code + configs to both Pis and restarts `pi_api`.
2. Re-initializes the projector on the Follower.
3. Leader generates the stimulus plan (applying the warp/intensity correction).
4. Leader pushes the stim NPZ to the Follower.
5. Controller renders thumbnails for preview.

**GO enables only after a successful deploy**, and one GO is spent per Deploy — after a
session you must Deploy again before you can start another.

Editing any task parameter after a Deploy invalidates it: the phase drops back to
**Connected**, GO greys out and Deploy re-arms, with a note in the Log. The Pis still hold
the previously deployed YAML and stimulus plan, so a re-Deploy is required before GO.

### Step 7 — GO

Click **GO**. The session starts:
- Leader runs the imperative trial loop trial by trial.
- Follower renders stimuli on the projector.
- Camera records to disk (or previews only, per Step 5).
- Events stream to the controller via UDP for the dashboard.

### Step 8 — Monitor

| Indicator | What it means |
|---|---|
| Session monitor | Current trial / block count |
| Lick Sensor | Total lick count |
| Reward | Last pulse duration |
| Display | Current trial on Follower |
| Events raster | Green ticks = licks, blue = rewards, purple = timeouts, stim on/off |
| Trial table | Per-trial outcome (hit/miss) |

The session aborts on its own if `session.global_timeout_trials` is reached (mouse dry
for N consecutive trials — see below).

**To abort manually:** Click **STOP** — ends the trial loop cleanly.

### Step 9 — Sync the data (Data tab)

The session stays on the Leader. In the **Data** tab, load the rig (or its group), then
**Sync Now** and pick the mouse/date folders (unsynced ones are red and pre-selected) — or, at
the end of the day, **Sync & Poweroff**, which copies everything unsynced and then powers off
every Pi of the selected rigs. Consolidation into one self-contained `<session>.h5` happens on
the Leader before the copy; the copy is verified with a second rsync pass.

**Destination:** the Data root (`data_root` in `controller/configs/controller.yaml`; else `$VRFARM_DATA_DIR`, else
`~/VRFarm/data`), the same tree for every rig:
```
<data root>/<subject>/<subject>_<date>/<session_id>/
  <session_id>.h5      <- consolidated: trials, stim plan, per-device data, camera ts, metadata
  video.mp4            <- behavior video (only if camera was saved; remuxed from the .h264)
```

The subject index `<data root>/subjects/<subject_id>.json` is written when the session ends
(with the rig name), not at sync. **Purge Data** deletes synced, consolidated folders from the
Pi; the **Auto purge** switch does that right after each verified sync. Details:
[MULTI_RIG.md](MULTI_RIG.md).

---

## Task Parameters

A task YAML has four sections. Values below are the current defaults from
`experiments/_template.yaml` (the only task file in git); the code that reads them is
`engine/leader.py`, `shared/stim_generator.py`, and `devices/reward.py`.
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

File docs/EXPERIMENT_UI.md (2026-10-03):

# Experiment UI — running a session

**Last updated:** 2026-08-17

This is the tab you use every experiment day: pick a subject and a task, push it to the
rig, run the session, and watch the animal behave in real time. Pulling the data back is the
**Data** tab's job ([MULTI_RIG.md](MULTI_RIG.md)); building or servicing the rig itself happens
in the [Setup tab](SETUP_UI.md). Each loaded rig is a sub-tab; the **Load rig** menu also loads
whole groups.

```bash
conda activate vrfarm
python controller/app.py     # http://localhost:5000 -> Experiment tab
python controller/app.py --port 5055 --no-browser    # if AirPlay owns 5000 (macOS)
```
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

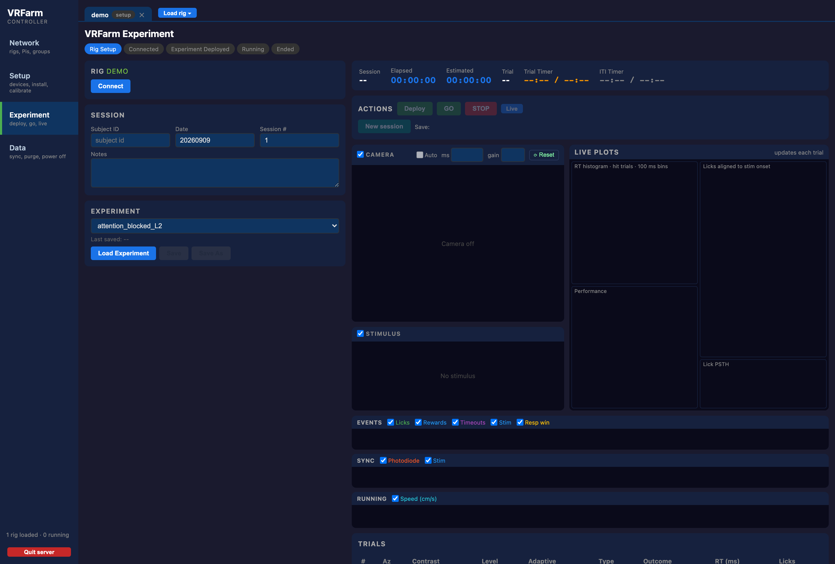
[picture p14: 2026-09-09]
docs/images/shell-02-experiment-tab.png

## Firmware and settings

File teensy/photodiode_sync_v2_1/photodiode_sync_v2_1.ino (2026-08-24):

/*
 * photodiode_sync_v2_1.ino  —  Teensy 4.x photodiode sync-pulse detector   (VERSION v2_1)
 *
 * v2_1 adds an ALWAYS-ON serial stream of the photodiode voltage V — one bare float per line at
 * 100 Hz — so the LEADER Pi can monitor signal quality and validate the display->diode sync path
 * at init. Connect the Teensy USB to the LEADER Pi (it runs the photodiode device); the TTL pulse
 * wire (OUT_PIN -> leader GPIO) is unchanged, so the Teensy reaches the leader two ways: USB (V
 * stream, new) + the pulse wire (timing). The stream is independent of DEBUG, which stays a
 * separate Serial-Plotter tuning tool (off by default).
 *
 * Reads the photodiode voltage on an analog pin, thresholds it, applies the SAME two
 * filters as the VRFarm setup UI, and emits a clean 3.3V square pulse to the RPi GPIO
 * on each detected sync pulse. Teensy's 3.3V logic drives the RPi input directly (no
 * level issues), fixing the "photodiode ~2V < Pi logic-high" problem.
 *
 *   Filter 1  STEADY / glitch  (= setup UI "Steady filter", glitch_ms 0.5 ms):
 *             the thresholded level must HOLD for STEADY_US before an edge counts.
 *             Drops spikes narrower than this; also delays every edge by this amount.
 *   Filter 2  HOLD-OFF          (= setup UI "Hold-off", debounce_ms 5 ms):
 *             after an accepted pulse, ignore further pulses for HOLDOFF_US.
 *             Kills the spike->plateau double-trigger and ringing.
 *
 * ── ADAPTIVE THRESHOLDS ──────────────────────────────────────────────────────
 * The photodiode baseline drifts (idles anywhere from ~1V to ~2V, always < 3V). With
 * ADAPTIVE=1 the two Schmitt thresholds are no longer fixed voltages — they RIDE on a
 * live estimate of the signal, so they self-adjust to whatever level the diode idles at
 * (and to whatever height the pulse reaches):
 *
 *   baseline follower : an asymmetric 1-pole filter that chases the signal's FLOOR fast
 *                       but rises SLOWLY, so brief upward pulses barely move it while real
 *                       baseline drift is still tracked.  (mirror for active-low)
 *   peak follower     : the opposite — jumps to a new pulse TIP fast, relaxes back slowly.
 *   thresholds        : placed a fixed FRACTION of the way from baseline to peak
 *                       (START_FRAC to begin a pulse, END_FRAC < START_FRAC to end it —
 *                       the gap is the hysteresis dead-band).
 *   MIN_PULSE guard   : a real pulse must rise at least MIN_PULSE_V above the baseline;
 *                       smaller excursions are ignored and the START threshold is pinned
 *                       here, so the thresholds can't sink into the noise when the flashes
 *                       pause (the peak decays but START stays put).  <-- the safety valve.
 *   baseline freeze   : while a pulse is active the elevated samples are NOT fed to the
 *                       baseline follower, so the pulse itself can't drag the baseline up.
 *
 * Set ADAPTIVE=0 to fall back to the original fixed THRESHOLD_HI_V / THRESHOLD_LO_V.
 *
 * ⚠️  HARDWARE: Teensy 4 analog pins are 3.3V MAX and NOT 5V-tolerant. Your photodiode
 *     swings >5V — you MUST divide/clamp the input below 3.3V before PD_PIN (e.g. a
 *     resistor divider, or a Schottky clamp to 3V3). Set DIVIDER below to your divider
 *     ratio so DEBUG prints the true photodiode voltage.
 *
 * TUNING (DEBUG=1 opens the Serial Plotter with:  1 = raw V,  2 = live START threshold,
 *     3 = live END threshold,  4 = detection marker.  The onboard LED also mirrors the
 *     output in DEBUG builds. Run the setup-UI photodiode "Test"):
 *       • Watch traces 2 & 3 sit a little above the idle level and track it as the baseline
 *         drifts. Each real flash (trace 1 spike) should punch above trace 2, then fall
 *         back below trace 3 → trace 4 pops to full-scale.
 *       • If the thresholds sit too high (flash never crosses trace 2): lower START_FRAC.
 *       • If they hug the noise and false-trigger while idle: raise MIN_PULSE_V (and/or
 *         START_FRAC). If they sag when flashes pause then snap back on the next flash,
 *         that's the MIN_PULSE floor working — raise MIN_PULSE_V if the sag dips too low.
 *       • Peak tracker slow to catch the tip: lower PEAK_RISE_TC_S. Noise spikes inflating
 *         it: raise PEAK_RISE_TC_S. Baseline chasing drift too slowly: lower BASELINE_RISE_TC_S.
 *     Then set DEBUG=0 and wire OUT_PIN to the RPi before porting.
 */

// ── Pins ─────────────────────────────────────────────────────────────────────
const int PD_PIN  = A1;   // photodiode analog input  (MUST be <= 3.3 V at the pin)
const int OUT_PIN = 16;    // digital square-pulse output -> RPi GPIO (idles LOW, pulses HIGH)
const int LED_PIN = 13;   // onboard LED mirrors the output — DEBUG builds only (quick visual check)

// ── ADC / scaling ────────────────────────────────────────────────────────────
const int   ADC_BITS = 12;     // 12-bit -> 0..4095
const float ADC_VREF = 3.3f;   // Teensy 4 analog reference (volts, fixed)
const float DIVIDER  = 1.0f;   // input scale-down ratio (e.g. 2.0 for a 2:1 divider).
                               // Detection uses the PIN voltage; DEBUG also prints pin_V * DIVIDER.

// ── Detection: adaptive vs fixed ─────────────────────────────────────────────
const bool  ACTIVE_HIGH = true;    // true: pulse = signal ABOVE baseline; false: BELOW
const bool  ADAPTIVE    = true;    // true: thresholds track the live baseline/peak (below);
                                   // false: use the fixed THRESHOLD_*_V pair (original behaviour).

// Fixed thresholds — used ONLY when ADAPTIVE == false.
const float THRESHOLD_HI_V = 1.8f;
const float THRESHOLD_LO_V = 0.6f;

// ── Adaptive tracker tuning (used when ADAPTIVE == true) ─────────────────────
// Time constants are in seconds. "fast" = small TC, "slow" = large TC. Values below assume
// a ~1.3 ms pulse at 60 Hz; adjust with the Serial Plotter (see TUNING above).
const float BASELINE_FALL_TC_S = 0.05f;  // baseline chases the FLOOR this fast (snappy).
const float BASELINE_RISE_TC_S = 4.0f;   // baseline creeps UP this slow. (With the pulse freeze
                                         // below this now only governs idle drift — shorten for
                                         // quicker recovery after a real baseline shift.)
const float PEAK_RISE_TC_S     = 0.01f;  // peak jumps to a new TIP this fast.
const float PEAK_FALL_TC_S     = 2.0f;   // peak relaxes back this slow -> survives missed pulses.
const float START_FRAC = 0.60f;          // begin a pulse at 60% of the baseline->peak span.
const float END_FRAC   = 0.30f;          // end it back at 30%   (END < START = hysteresis band).
const float MIN_PULSE_V = 0.30f;         // guard: a real pulse must rise at least this far above the
                                         // baseline. Smaller excursions are ignored, and this is the
                                         // floor (on the START offset) that stops the thresholds
                                         // collapsing into the noise when the flashes pause.

// ── Filters ──────────────────────────────────────────────────────────────────
const uint32_t STEADY_US  = 150;    // Filter 1: steady/glitch — MUST be << the pulse's time-above-
                                    // threshold (~1.2 ms). 150 µs drops fast spikes, passes the pulse.
const uint32_t HOLDOFF_US = 5000;   // Filter 2: hold-off — > the 1.5 ms pulse (kills falling-edge
                                    // ringing), << the inter-pulse interval (>=16.7 ms at 60 Hz).

// ── Output pulse to the RPi ──────────────────────────────────────────────────
const uint32_t OUT_PULSE_US = 5000; // width of the square pulse (µs). Must be >> the RPi's
                                    // glitch filter (0.5 ms) and << the inter-pulse interval.

// ── Debug ────────────────────────────────────────────────────────────────────
#define DEBUG 0                       // 1 = stream "V start end detect" (4 traces) + pulse the LED; 0 = silent (production)
const uint32_t DEBUG_PERIOD_US = 200;   // V print interval (µs); 200 = 5 kHz so a ~1.3 ms pulse shows ~6-7
                                        // points (Teensy USB ignores baud). Detection uses EVERY sample regardless.

// ── Always-on V stream (v2_1) ────────────────────────────────────────────────
// Independent of DEBUG: when DEBUG is OFF, print the BARE photodiode voltage — one float per line,
// nothing else — at STREAM_PERIOD_US so the leader Pi parses it with float(line) for V-range
// monitoring and the init sync check. Detection/output are unaffected. (When DEBUG is ON the
// 4-trace plotter stream is emitted instead, whose first field is also V.)
const uint32_t STREAM_PERIOD_US = 10000;   // 10 ms = 100 Hz

// ── State ────────────────────────────────────────────────────────────────────
int      hiCounts, loCounts;     // hysteresis thresholds in ADC counts (LIVE when adaptive, else set in setup)
float    floorCounts = 0;        // asymmetric follower: signal FLOOR  (ADC counts, kept as float)
float    ceilCounts  = 0;        // asymmetric follower: signal CEILING (ADC counts, kept as float)
uint32_t lastSampleUs = 0;       // dt source for the followers
bool     hyst         = false;   // Schmitt-trigger output — instantaneous level
bool     steadyActive = false;   // level after the steady filter (== "pulse detected now")
uint32_t hystChangeUs = 0;       // when hyst last changed
uint32_t lastAcceptUs = 0;       // when we last accepted a pulse (for hold-off)
bool     outActive    = false;   // output square pulse currently HIGH
uint32_t outStartUs   = 0;
uint32_t lastDebugUs  = 0;
uint32_t lastStreamUs = 0;       // v2_1: gates the always-on bare-V serial stream
uint32_t pulseCount   = 0;

static inline float countsToVolts(int c)   { return c * ADC_VREF / ((1 << ADC_BITS) - 1); }
static inline float countsToVolts(float c) { return c * ADC_VREF / ((1 << ADC_BITS) - 1); }

void setup() {
  pinMode(OUT_PIN, OUTPUT);  digitalWriteFast(OUT_PIN, LOW);
  pinMode(LED_PIN, OUTPUT);  digitalWriteFast(LED_PIN, LOW);   // configured + parked low; only pulsed in DEBUG builds
  analogReadResolution(ADC_BITS);
  analogReadAveraging(8);                    // light averaging for a steadier threshold
  Serial.begin(115200);

  // Seed the followers near the real signal (~50 ms average) so they don't start at 0 and
  // false-trigger while converging. If flashes are already running the seed sits a hair high;
  // the floor follower settles it within BASELINE_FALL_TC_S. Best to seed before the flash test.
  double acc = 0; const int N = 500;
  for (int i = 0; i < N; i++) { acc += analogRead(PD_PIN); delayMicroseconds(100); }
  floorCounts = ceilCounts = (float)(acc / N);

  // Fixed-threshold fallback (used only when ADAPTIVE == false).
  hiCounts = (int)(THRESHOLD_HI_V / ADC_VREF * ((1 << ADC_BITS) - 1));
  loCounts = (int)(THRESHOLD_LO_V / ADC_VREF * ((1 << ADC_BITS) - 1));

  lastSampleUs = micros();
}

void loop() {
  const uint32_t now = micros();
  const int counts   = analogRead(PD_PIN);

  // ── Adaptive tracking: update the followers and recompute the LIVE thresholds ───────────────
  // Two asymmetric one-pole followers bracket the signal. alpha = dt/(TC+dt) turns each time
  // constant into a per-sample blend factor, self-correcting for the loop's actual sample rate.
  //   floorCounts : fast DOWN, slow UP   -> tracks the idle floor, ignores upward pulses.
  //   ceilCounts  : fast UP,   slow DOWN -> tracks the pulse tip, survives a few missed pulses.
  // Thresholds are then a fraction of the baseline->peak span, with the START offset floored at
  // MIN_PULSE_V. Skipped entirely when ADAPTIVE == false (fixed hiCounts/loCounts from setup()).
  if (ADAPTIVE) {
    const float dt = (now - lastSampleUs) * 1e-6f;   // seconds since last sample
    lastSampleUs = now;
    const float x = (float)counts;

    const float aFloorDown = dt / (BASELINE_FALL_TC_S + dt);
    const float aFloorUp   = dt / (BASELINE_RISE_TC_S + dt);
    const float aCeilUp    = dt / (PEAK_RISE_TC_S     + dt);
    const float aCeilDown  = dt / (PEAK_FALL_TC_S     + dt);

    // Freeze the BASELINE follower while a pulse is active (hyst high) so the elevated samples can't
    // drag it up. A sample that's beyond the baseline in the *idle* direction is still let through
    // (it can't be part of the pulse, and it keeps the estimate from sticking). The PEAK follower
    // always updates: mid-pulse is exactly when it should catch the tip. (hyst here is the previous
    // sample's state; the 1-sample lag at ~20 kHz is negligible.)
    const bool inPulse = hyst;
    if (ACTIVE_HIGH) {                                        // baseline = floor
      if (!inPulse || x < floorCounts)
        floorCounts += ((x < floorCounts) ? aFloorDown : aFloorUp) * (x - floorCounts);
      ceilCounts += ((x > ceilCounts) ? aCeilUp : aCeilDown) * (x - ceilCounts);
    } else {                                                  // baseline = ceiling
      if (!inPulse || x > ceilCounts)
        ceilCounts += ((x > ceilCounts) ? aCeilUp : aCeilDown) * (x - ceilCounts);
      floorCounts += ((x < floorCounts) ? aFloorDown : aFloorUp) * (x - floorCounts);
    }

    // Thresholds sit a fraction of the way baseline->peak, but the START offset is floored at
    // MIN_PULSE_V: a sub-0.2 V excursion (or a peak that has decayed because the flashes paused)
    // can never reach START, which is what keeps the thresholds from collapsing into the noise.
    // The END offset is scaled down with it so the hysteresis band keeps its shape.
    float span = ceilCounts - floorCounts;
    if (span < 0) span = 0;
    const float minPulse = MIN_PULSE_V / ADC_VREF * ((1 << ADC_BITS) - 1);
    float startOff = START_FRAC * span;
    float endOff   = END_FRAC   * span;
    if (startOff < minPulse) { startOff = minPulse; endOff = minPulse * (END_FRAC / START_FRAC); }

    if (ACTIVE_HIGH) {                                 // baseline = floor; pulse rides UP
      hiCounts = (int)(floorCounts + startOff);        // START (higher magnitude)
      loCounts = (int)(floorCounts + endOff);          // END
    } else {                                           // baseline = ceiling; pulse dips DOWN
      hiCounts = (int)(ceilCounts - endOff);           // END (shallow -> higher magnitude)
      loCounts = (int)(ceilCounts - startOff);         // START (deep -> lower magnitude)
    }
  }

  // ── Schmitt trigger (hysteresis comparator) -> instantaneous level ──────────────────────────
  // A plain single-threshold comparator chatters when a noisy/inflected signal sits near the
  // threshold: every notch that dips back across it looks like a fresh edge. A Schmitt trigger uses
  // TWO thresholds plus one bit of memory (`hyst`):
  //     - while INACTIVE it ignores everything until the signal crosses UP past hiCounts   -> active
  //     - while ACTIVE   it stays active until the signal falls DOWN past loCounts          -> inactive
  //     - in the dead band (loCounts < x < hiCounts) it HOLDS the previous state.
  // So the fast downward notches in the pulse plateau — which stay above loCounts — never flip the
  // state, and the whole pulse reads as one clean level. (hiCounts/loCounts are now the LIVE,
  // baseline-relative thresholds when ADAPTIVE, or the fixed ones otherwise — the logic is identical.)
  const bool prevHyst = hyst;
  if (ACTIVE_HIGH) {
    if (counts >= hiCounts)      hyst = true;    // rise past HI -> start
    else if (counts <= loCounts) hyst = false;   // fall past LO -> end   (else: hold, in dead band)
  } else {                                       // active-low: pulse is a downward excursion
    if (counts <= loCounts)      hyst = true;
    else if (counts >= hiCounts) hyst = false;
  }
  if (hyst != prevHyst) hystChangeUs = now;

  // ── Filter 1: steady — commit the Schmitt level only after it holds STEADY_US ──
  if (hyst != steadyActive && (now - hystChangeUs) >= STEADY_US) {
    const bool rising = (hyst && !steadyActive);   // edge INTO the active state
    steadyActive = hyst;

    // ── Filter 2: hold-off — accept a rising edge only outside the refractory window ──
    if (rising && (now - lastAcceptUs) >= HOLDOFF_US) {
      lastAcceptUs = now;
      pulseCount++;
      outActive = true; outStartUs = now;
      digitalWriteFast(OUT_PIN, HIGH);
#if DEBUG
      digitalWriteFast(LED_PIN, HIGH);   // onboard LED mirrors the output — DEBUG builds only
#endif
    }
  }

  // Finish the output square pulse after OUT_PULSE_US.
  if (outActive && (now - outStartUs) >= OUT_PULSE_US) {
    outActive = false;
    digitalWriteFast(OUT_PIN, LOW);
#if DEBUG
    digitalWriteFast(LED_PIN, LOW);
#endif
  }

#if !DEBUG
  // ── v2_1 always-on stream: bare photodiode voltage @ 100 Hz for the leader Pi. One float per
  //    line, nothing else. (Suppressed when DEBUG is on — the 4-trace block below carries V then.)
  if (now - lastStreamUs >= STREAM_PERIOD_US) {
    lastStreamUs = now;
    Serial.println(countsToVolts(counts) * DIVIDER, 3);
  }
#endif

#if DEBUG
  // Four space-separated values per line -> four traces in the Arduino Serial Plotter:
  //   trace 1 = raw photodiode volts.
  //   trace 2 = live START threshold (crossed UP to begin a pulse).
  //   trace 3 = live END threshold   (crossed back DOWN to end it). Traces 2/3 straddle the pulse
  //             and, in ADAPTIVE mode, visibly track the baseline as it drifts.
  //   trace 4 = detection marker, pinned to full-scale while a pulse is accepted (after both filters).
  // If trace 1's flash never reaches trace 2 -> lower START_FRAC (adaptive) or THRESHOLD_HI_V (fixed).
  // If traces 2/3 hug the noise and trace 4 flickers while idle -> raise MIN_PULSE_V (adaptive).
  if (now - lastDebugUs >= DEBUG_PERIOD_US) {
    lastDebugUs = now;
    Serial.print(countsToVolts(counts)   * DIVIDER, 3);  Serial.print(' ');
    Serial.print(countsToVolts(hiCounts) * DIVIDER, 3);  Serial.print(' ');
    Serial.print(countsToVolts(loCounts) * DIVIDER, 3);  Serial.print(' ');
    Serial.println(steadyActive ? (ADC_VREF * DIVIDER) : 0.0f, 3);
  }
#endif
}

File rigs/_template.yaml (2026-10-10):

# Template for a new rig (Network tab -> Add rig). Devices/ports mirror the live rig;
# pis are filled in from the form. Not a rig itself: files starting with '_' are skipped.
data:
  leader_dir: /home/vruser/data
  video_dir: /media/vruser/ssd/video
  # video_mount: /media/vruser/ssd   # only if video_dir is on its own drive: the Data tab then
  #                                  # trusts (and purges) the video tree only while it is mounted
devices:
  camera:
    auto_exposure: false
    bit_depth: 8
    bitrate_mbps: 6
    enabled: true
    exposure_ms: 10
    fps: 60
    gain: 2.0
    gop_s: 5.0
    h264_profile: main
    live_preset: high
    resolution:
    - 1014
    - 760
    sensor_mode:
    - 2028
    - 1520
    type: camera
  display:
    apply_warp: true
    enabled: true
    geometry_file: rig_geometry.yaml
    refresh_hz: 57.46
    resolution:
    - 1920
    - 1080
    type: display
  encoder:
    enabled: true
    i2c_address: '0x36'
    i2c_bus: 1
    sample_hz: 500
    type: encoder
    wheel_diameter_cm: 14.4
  lick_sensor:
    electrode: 4
    enabled: true
    i2c_address: '0x5A'
    type: lick_sensor
  photodiode:
    enabled: true
    gpio: 16
    pulse_every_n_frames: 5
    # the Teensy's USB serial. Use the by-id name (ls /dev/serial/by-id/ on the leader): ttyACM<n>
    # is handed out in enumeration order and moved after a reboot.
    serial_port: /dev/serial/by-id/usb-Teensyduino_USB_Serial_<serial>-if00
    sync_brightness: 1.0
    sync_corner: top-right
    sync_size_px: 150
    type: photodiode
    v_high: 3.0
    v_low: 0.3
    v_realert_s: 30.0
    v_window_s: 10.0
    verify_duration_s: 1.0
    verify_enabled: true
  reward:
    calibration:
      main:
      - - 10
        - 4
    enabled: true
    pins:
      home:
        gpio: 24
        label: home
      main:
        gpio: 23
        label: reward
    reward_type: sucrose
    type: reward
grace_period_s: 10
name: _template
network:
  api_port: 5080
  event_port: 5571
  command_port: 5572
  ack_port: 5573
  display_port: 5575
  displayd_pd_port: 5582
  camera_port: 5001
pis: []
slack:
  enabled: false
  webhook_url: ''
shepherd:
  enabled: true

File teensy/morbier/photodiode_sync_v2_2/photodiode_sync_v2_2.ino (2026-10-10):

/*
 * photodiode_sync_v2_2.ino  —  Teensy 4.x photodiode sync-pulse detector   (VERSION v2_2)
 *
 * v2_2 replaces v2_1's 100 Hz bare-V stream with PER-PULSE amplitude reports. The old
 * stream sampled at random phase while the optical pulses are ~1-2 ms wide, so most
 * samples landed in the dark between pulses and percentile monitoring on the Pi was
 * aliased garbage (bench 2026-08-22: p99 varied 0.12-2.7 V across identical runs).
 * The detection loop samples at full rate and sees every sample of every pulse, so the
 * amplitude statistics are computed HERE and shipped as one line per accepted pulse:
 *
 *     P <median_V> <peak_V> <baseline_V> <width_us>
 *
 *   median_V   robust pulse level — the "is the signal too low/too high" number
 *   peak_V     clipping check: the pin saturates at 3.3 V; flag peaks >= ~3.0 V
 *   baseline_V floor-follower level at pulse start; median-baseline = true pulse height
 *   width_us   time above threshold — a real optical sub-pulse is ~1-1.5 ms; mains-hum
 *              crossings are ~10 ms (bench-proven fault discriminator)
 *
 * Plus one idle line per second (covers amp-off / ground-fault / ambient-light faults,
 * which live OUTSIDE pulses — bench-proven three times):
 *
 *     B <floor_V> <ceil_V>
 *
 * The Pi-side rules this enables: peak_V >= 3.0 -> "too high / clipping" safety warning;
 * median_V - baseline_V small (approaching MIN_PULSE_V) -> "too low" warning; no P lines
 * while flashes are commanded -> optical path dead; P lines with width ~10 ms -> hum.
 * NOTE: the v2_1/main-branch parser (devices/photodiode.py float(first-field)) skips
 * tagged lines silently — update the parser alongside deploying this firmware.
 *
 * Detection logic (adaptive thresholds, steady filter, hold-off, output pulse) is
 * UNCHANGED from v2_1. DEBUG mode (4-trace Serial Plotter) is unchanged.
 *
 * ── ADAPTIVE THRESHOLDS ──────────────────────────────────────────────────────
 * The photodiode baseline drifts. With ADAPTIVE=1 the two Schmitt thresholds RIDE on a
 * live estimate of the signal:
 *   baseline follower : asymmetric 1-pole filter chasing the FLOOR fast, rising slowly.
 *   peak follower     : the opposite — jumps to a new pulse TIP fast, relaxes slowly.
 *   thresholds        : a fixed FRACTION of the baseline->peak span (START_FRAC/END_FRAC).
 *   MIN_PULSE guard   : a real pulse must rise >= MIN_PULSE_V above baseline; pins the
 *                       START threshold so it can't sink into noise when flashes pause.
 *   baseline freeze   : pulse samples are not fed to the baseline follower.
 *
 * ⚠️  HARDWARE: Teensy 4 analog pins are 3.3V MAX and NOT 5V-tolerant. Divide/clamp the
 *     photodiode below 3.3V before PD_PIN. The TTL output is Teensy pin 16 (OUT_PIN),
 *     wired to the leader Pi's GPIO16 — scope-verified on the rig 2026-08-23 (the old
 *     docs said Teensy pin 1; the physical wire is on pin 16).
 */

// ── Pins ─────────────────────────────────────────────────────────────────────
const int PD_PIN  = A0;   // morbier: photodiode amp on A0 (MUST be <= 3.3 V at the pin)
const int OUT_PIN = 3;    // morbier: TEENSY pin 3 -> leader Pi GPIO16 (idles LOW)
const int LED_PIN = 13;   // onboard LED mirrors the output — DEBUG builds only

// ── ADC / scaling ────────────────────────────────────────────────────────────
const int   ADC_BITS = 12;     // 12-bit -> 0..4095
const float ADC_VREF = 3.3f;   // Teensy 4 analog reference (volts, fixed)
const float DIVIDER  = 1.0f;   // input scale-down ratio (reported voltages are pin_V * DIVIDER)

// ── Detection: adaptive vs fixed ─────────────────────────────────────────────
const bool  ACTIVE_HIGH = true;
const bool  ADAPTIVE    = true;

// Fixed thresholds — used ONLY when ADAPTIVE == false.
const float THRESHOLD_HI_V = 1.1f;
const float THRESHOLD_LO_V = 0.3f;

// ── Adaptive tracker tuning ──────────────────────────────────────────────────
const float BASELINE_FALL_TC_S = 0.05f;
const float BASELINE_RISE_TC_S = 4.0f;
const float PEAK_RISE_TC_S     = 0.01f;
const float PEAK_FALL_TC_S     = 2.0f;
const float START_FRAC  = 0.60f;
const float END_FRAC    = 0.30f;
const float MIN_PULSE_V = 0.15f;   // morbier: flashes 0.34 V above floor, black-level red segments 0.07 V

// ── Filters ──────────────────────────────────────────────────────────────────
const uint32_t STEADY_US  = 150;
// One TTL edge per COMMANDED FLASH, not per DLP colour sub-pulse.
//
// Measured on the rig 2026-08-24 (DEBUG capture, 58k samples at 4.8 kHz, every_n=5):
// one sync-square frame produces **4 optical sub-pulses spaced 4.34 ms** (230 Hz red
// segment rate), so the burst spans ~14 ms; flashes repeat every 87.0 ms (= 5/57.46).
// HOLDOFF_US was 5000 — i.e. INSIDE that 4.34 ms train — so it accepted sub-pulses 1
// and 3 and dropped 2 and 4: exactly 2 edges per flash, by accident of 5 ms vs 4.34 ms.
//
// That mattered because devices/photodiode.py's init verify is "missing-only"
// (detected >= emitted - 1). At 2 edges per flash, HALF the flashes could fail and the
// count still passed. At 1:1 a single missed flash is visible.
//
// Constraint: sub-pulse train (<=4 x 4.34 + 1.2 ~= 18.6 ms) < HOLDOFF < flash period
// (every_n / 57.46). 30 ms gives 1.6x over the train and 2.9x under the 87 ms period.
// ⚠️ If photodiode_sync_every_n drops below 3 (52 ms) this must come down with it.
const uint32_t HOLDOFF_US = 30000;

// ── Output pulse to the RPi ──────────────────────────────────────────────────
const uint32_t OUT_PULSE_US = 5000;

// ── Debug ────────────────────────────────────────────────────────────────────
#define DEBUG 0                       // 1 = 4-trace Serial Plotter stream; 0 = production (P/B lines)
const uint32_t DEBUG_PERIOD_US = 200;

// ── v2_2 reporting ───────────────────────────────────────────────────────────
const uint32_t BASELINE_PERIOD_US = 1000000;  // "B <floor_V> <ceil_V>" once per second
const int      PULSE_BUF_MAX      = 256;      // samples kept for the median (a ~1.3 ms pulse
                                              // at the ~15-20 kHz loop rate is ~20-30 samples;
                                              // a 10 ms hum crossing still fits)

// ── State ────────────────────────────────────────────────────────────────────
int      hiCounts, loCounts;
float    floorCounts = 0;
float    ceilCounts  = 0;
uint32_t lastSampleUs = 0;
bool     hyst         = false;
bool     steadyActive = false;
uint32_t hystChangeUs = 0;
uint32_t lastAcceptUs = 0;
bool     outActive    = false;
uint32_t outStartUs   = 0;
uint32_t lastDebugUs  = 0;
uint32_t lastBaselineUs = 0;   // v2_2: gates the 1 Hz baseline line
uint32_t pulseCount   = 0;
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

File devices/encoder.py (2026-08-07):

"""
devices/encoder.py

Running-wheel encoder via an Adafruit AS5600 magnetic angle sensor (I2C, addr 0x36).
A diametric magnet on the wheel axle spins over the chip; we poll the 12-bit absolute
angle, UNWRAP it over time into cumulative rotation, and derive running distance (cm)
and speed (cm/s). The full running trace is saved to the session HDF5.

I/O: I2C (smbus2). Polls RAW ANGLE (reg 0x0C/0x0D); STATUS (0x0B) reports magnet presence.
"""

from __future__ import annotations
import math
import threading
import time
from array import array

from .base import Device, DeviceInfo, IOType, register_device

# AS5600 registers
_REG_RAW_ANGLE = 0x0C   # 2 bytes, 12-bit (0..4095) = 0..360 deg
_REG_STATUS = 0x0B      # bit5 MD=magnet detected, bit4 ML=too strong, bit3 MH=too weak
_COUNTS_PER_REV = 4096


@register_device
class Encoder(Device):
    info = DeviceInfo("encoder", "Running Wheel", IOType.I2C, ["smbus2"])

    def init(self, rig_config: dict, task_params: dict):
        import smbus2
        addr_raw = rig_config.get("i2c_address", "0x36")
        self.addr = int(addr_raw, 16) if isinstance(addr_raw, str) else addr_raw
        self.i2c_bus = rig_config.get("i2c_bus", 1)
        self.wheel_diameter_cm = float(rig_config.get("wheel_diameter_cm", 15.0))
        self.circ_cm = math.pi * self.wheel_diameter_cm     # wheel circumference (1 rev = circ_cm)
        self.sample_hz = int(rig_config.get("sample_hz", 100))   # high enough that <½ turn/sample
        self.bus = smbus2.SMBus(self.i2c_bus)
        self._pub_period = 1.0 / 15.0        # throttle live events to ~15 Hz (full trace still saved)
        self._stream_active = False
        self._stream_thread = None
        # running state
        self._angle_prev = 0
        self._cum_counts = 0
        self._last_t = time.time()
        self._last_dist_cm = 0.0
        self._speed_ema = 0.0
        self._trial_dist0 = 0.0
        # session trace buffers (converted to arrays in hdf5_session_data)
        self._buf_t = array('d')
        self._buf_dist = array('f')
        self._buf_speed = array('f')
        self._buf_counts = array('q')   # cumulative signed counts (raw ground truth; rotations = counts/4096)

    def _read_raw_angle(self) -> int:
        data = self.bus.read_i2c_block_data(self.addr, _REG_RAW_ANGLE, 2)
        return ((data[0] & 0x0F) << 8) | data[1]     # 12-bit, 0..4095

    def check(self) -> dict:
        try:
            status = self.bus.read_byte_data(self.addr, _REG_STATUS)
            md = bool(status & 0x20)     # magnet detected
            too_strong = bool(status & 0x10)
            too_weak = bool(status & 0x08)
            angle = self._read_raw_angle() * 360.0 / _COUNTS_PER_REV
            msg = "magnet OK" if md else "magnet NOT detected"
            if too_strong:
                msg += " (too close)"
            if too_weak:
                msg += " (too far)"
            msg += f", angle={angle:.1f}deg"
            return {"ok": md, "message": msg}
        except Exception as e:
            return {"ok": False, "message": str(e)}

    def start_stream(self, callback):
        """Poll the AS5600 at sample_hz, unwrap the angle into cumulative rotation, and derive
        distance (cm) + speed (cm/s). Emits throttled {"event":"running", ...} for the live UIs and
        accumulates the full trace for hdf5_session_data()."""
        self._stream_active = True
        try:
            self._angle_prev = self._read_raw_angle()
        except Exception:
            self._angle_prev = 0
        self._cum_counts = 0
        self._last_t = time.time()
        self._last_dist_cm = 0.0
        self._speed_ema = 0.0
        self._trial_dist0 = 0.0
        self._buf_t = array('d')
        self._buf_dist = array('f')
        self._buf_speed = array('f')
        self._buf_counts = array('q')
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

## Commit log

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2026-07-20 Fixed the blank gray to be in the range of 0 to 1, strictly. From fully dark to fully bright.
    [display.py]
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2026-07-20 Add manual exposure/gain controls to the IR camera (setup UI)
    The mono IMX296 preview shows drifting horizontal readout banding,
    amplified by auto-gain running high on IR-dark scenes. Add fixed
    exposure/gain as live-tunable variables so the sensor can run at low
    gain (the lever that suppresses the banding).
    - devices/camera.py: auto_exposure/exposure_us/gain read in init (like
    bitrate_mbps); _exposure_controls() maps them to libcamera
    AeEnable/ExposureTime/AnalogueGain, applied at configure time and live
    via set_live_controls()/apply_exposure().
    - pi_api/api.py: /api/camera_controls endpoint (serialized on
    _camera_lock, refuses to mutate a live session recording);
    camera_preview_s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
    [api.py, camera.py]
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2026-07-21 Camera: experiment preview via decoupled lores stream at the live preset
    Consumes the experiment live-view preset and fixes the recording-side N1
    buffer-starvation freeze.
    - devices/camera.py: during a recording session, configure a small decoupled
    'lores' (YUV420) stream and serve the MJPEG preview from its Y-plane at the
    live preset (fps/scale/quality), so capture_array() no longer competes with
    the H264 encoder on 'main' (the video saves full-quality). PRESETS map
    high/med/low -> fps+scale+quality; _scaled_size derives an even lores size
    from the recording resolution; the Y-plane crop uses the size libcamera
    actually configured. start_preview gains downsample= so the experime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
    [api.py, camera.py]
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2026-07-22 Now can select from different methods of contrast calculation. Safety checks and correction options for thepretical contrast values and 8-bit code based snapping of contrast values
    [api.py, leader.py]
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2026-07-22 Fixed pi_api restarts. Fixed stimulus test bugs. Added independent bottom and up screen boundary.
    [api.py, display.py]
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2026-08-03 Serialize reward valve access to prevent GPIO races
    A pulse/train ran in a daemon thread with no lock, so a concurrent
    trigger (manual REWARD during an auto-reward train, or a double-press)
    could drive the same GPIO from two threads and garble the waveform.
    Add a non-blocking valve lock: a delivery already in flight is dropped
    instead of racing. A _stopping flag + finally guarantee the valve ends
    closed, and close() waits briefly for an in-flight train so pigpio is
    never disconnected mid-pulse (no stuck-open valve on STOP).
    [reward.py]
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2026-08-07 Fixed level 2 and 3 reward delivery logic. L2 is operant with pavlovian rescue. L3 is purely pavlovian.
    [leader.py]
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2026-08-09 Pi5 photodiode: resolve botched merge to lgpio + Teensy no-filter
    The dev-pi5 photodiode.py had been committed with unresolved conflict markers and still ran the old on-Pi steady/hold-off filters. Rewrite to main's Teensy no-filter logic on the lgpio backend, so it differs from main ONLY by the GPIO library.
    [photodiode.py]
2026-08-10 Stim speed: convert() cached surfaces, RAM-budgeted pre-warm, vsync-fallback frame cap, hardware-tick onset anchor
    #1 .convert() cached patch/field/checker surfaces -> format-matched fast blits. #2 pre-warm all unique stimulus surfaces at session start (bounded by ~40%% free RAM, 512MB hard cap) so the first show of each stimulus is a warm blit (fixes the cold-build onset hitch / missed sync). #3 Clock.tick(refresh_hz) fallback in _show_synced when vsync is refused. #5 anchor the photodiode true-onset from a main-thread (hardware tick, wall clock) pair instead of a jittery in-callback time.time().
    [display.py, photodiode.py]
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2026-08-12 Audit fixes (shared): loader robustness, empty data-dir guard, UI clamp, notebook comment
    From the since-yesterday code audit — the branch-identical (non-GPIO) files:
    - engine/leader.py: guard an empty/missing data.leader_dir. Path("") == "."
    silently wrote the session HDF5 into pi_api's cwd; now fall back to ~/data
    with a loud warning (the consolidate path already used `or` fallbacks).
    - analysis/loaders.py:
    * enforce the "format_version 2 only" contract instead of silently falling
    back to root for a legacy/flat file (which swept stray root datasets into
    the trial table);
    * _to_n(): fit optional per-trial device columns (reward_*, iti_lick_count)
    to n trials so a sess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
    [leader.py]
2026-08-12 Audit fixes (High): Reinit release-first + Install overlay/comment hardening
    From the since-yesterday code audit — the GPIO-divergent files (this is the
    dev-pi5 / lgpio variant; main gets the same fixes on its pigpio variant):
    - pi_api/api.py (HIGH): the per-card Reinit button (and a second Init Devices
    without a pi_api restart) re-created photodiode/calibration_probe/encoder/
    lick_sensor WITHOUT releasing the old instance first. For the lgpio devices
    the re-claim then failed "GPIO busy" and leaked a gpiochip fd; for the I2C
    devices it silently orphaned the old poll thread + bus handle. Add
    _release_one(name) — the single-device form of release_devices'
    stop_stream()->close(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
    [api.py]
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2026-08-12 Photodiode sync: draw the sync square during a run even without a warp map
    _draw_sync_border no-op'd whenever no warp was loaded (it needs the warp's
    valid_map to cap the square to the off-screen dead band), so on a rig with no
    warp yet the experiment never flashed the sync square -> no photodiode pulses
    during stimuli -> empty experiment-UI sync raster. The setup-UI flash test
    worked the whole time because it used _sync_test_rect(), which already has a
    pre-warp corner fallback. Point the experiment path at the same rect: warp-
    derived dead-band placement when a warp exists, plain corner square before one
    does. Pre-warp the square may sit inside the visible area (a warp puts it in
    the dead b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
    [display.py]
2026-08-12 Photodiode sync: force the pre-warp patch red-on-BLACK so the photodiode triggers
    Follow-up to the previous fix. Drawing the sync square without a warp put it on
    the bright green+blue stimulus field, so the corner toggled cyan->red — ~no
    change in total brightness, so a broadband photodiode never crossed the Teensy
    threshold (square visible, but zero TTL pulses). The setup flash test works
    precisely because it clears to black first. So in the no-warp fallback, paint
    the corner patch black on off-frames and red on flash frames (red-on-black =
    a real brightness spike). With a warp the dead band is already black, so that
    path is unchanged (red only when on). The pre-warp patch is visible to t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
    [display.py]
2026-08-12 Photodiode: anchor pulse clock to CLOCK_MONOTONIC (lgpio tick), not REALTIME
    reset_trial anchored the per-trial timebase with time.time_ns() (CLOCK_REALTIME)
    on the assumption that lgpio's alert tick is REALTIME. It isn't — the kernel GPIO
    event timestamp lgpio passes is CLOCK_MONOTONIC (ns since boot). The mismatch put
    every detected pulse ~1.7e9 s in the past, so:
    - the online onset sync never saw a pulse inside the 0.1 s window -> sync_ok=0
    every trial, true_onset_t left uncorrected;
    - the live experiment-UI sync raster plots on the session (REALTIME) clock, so
    the pulses landed astronomically off-screen -> "no pulses in the UI" even
    though 444 were detected and saved to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
    [photodiode.py]
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2026-08-17 Camera: record the mono sensor as YUV420, not RGB888
    The IMX296 is monochrome (Saturation=0), but the 'main' stream was configured
    RGB888 — so every frame the ISP expands mono to 3-channel RGB and the H264
    encoder converts RGB->YUV420 again. Configure 'main' as YUV420 (the encoder's
    native format) directly: skips the RGB round-trip -> real CPU relief on the
    Pi 5's SOFTWARE H.264 encoder (no HW encoder on Pi 5), helping it sustain fps.
    File size is unchanged (a grayscale source already has flat, near-free chroma
    in H.264). Safe: 'main' is read only by the encoder in start_recording, and is
    unread in start_preview (the preview always captures the lores Y-plane —
    _preview_source='lores' in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
    [camera.py]
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2026-08-23 Phase 0+1 of display rebuild: KMS config, unified deploy manifest, sync-chain fixes
    Phase 0: dlp/sample_config/config_kms.txt (byte-exact from the bench rig);
    shared/deploy_manifest.py as the single deploy list for both UIs.
    Phase 1: photodiode v2_2 P/B parser (split amplitude/baseline series, clip+hum
    warnings with recovery edges); verify fails on emitted<=0 and carries the
    follower's real error; leader binds ack_port 5573 and consumes stim_onset acks
    (select-guarded); experiment-UI photodiode init sends the full config via a
    shared payload builder (no optical verify at Load Rig — ordering); wiring docs
    corrected to Teensy pin 16; CLAUDE.md port map + cheese.yaml ack_port.
    Co-Authored-By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
    [config_kms.txt]
2026-08-23 Phase 2: displayd daemon + kmsdrm renderer + DLPC wrapper, service (disabled), Install steps
    Two-process design per the displayd spec: displayd.py (state machine, L1 poller
    with fault-bit latch tracking, renderer supervision, session/pd/REST sockets,
    sd_notify) + renderer.py child (sole DRM master, SCALED vsync contract, all
    display_worker actions + follower show path). dlpc.py wraps the vendored TI SDK
    defensively. devices/display.py gains the kms start path + flash_times capture.
    Install ships packages + the disabled unit + the KMS config candidate.
    Verified live on cheddar-dlp: full bringup to RENDERER_UP (KMSDRM 57.46 fps,
    flip 13.35 ms), sync_burst with flip timestamps, renderer kill->r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
    [display.py, displayd.py, dlpc.py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]
2026-08-23 Phase 3: daemon-mode pi_api forwarding + shim, leader-clocked L3 heartbeats, review fixes
    pi_api forwards every display endpoint to displayd when it is up (probe :5581),
    /api/start {script:follower} becomes a LOAD_STIMS shim (no spawn, old controllers
    keep working), /api/restart 409s under a session lease. Leader gains the L3
    heartbeat scheduler + single-clock correlator (cluster pulses, confirm against
    the reported flip), tri-state sync_ok, onset_source, and a named optics_watch_off
    degraded mode; heartbeat pulses are filtered out of the per-trial onset anchor.
    Gate-review fixes (8 finder angles): renderer now gets the composed display config
    (sync-square corner was defaulting wrong = sile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
    [api.py, displayd.py, dlpc.py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]
2026-08-24 L3: route display alarms to humans, localize the fault, abort on failure
    The L3 correlator worked but nothing downstream consumed it. leader
    published {"type":"display_health"} to the controller, whose listener
    handled only trial/shepherd_alert/global_timeout/session_end, so no
    Slack; the event reached the browser and fell through a switch with no
    case and no default. A dark projector was detected in 15 s and told
    no one.
    - app.py: display_health branch -> Slack, per-kind 60 s throttle,
    recovery re-arms it. display_abort pages immediately; an aborted
    session_end no longer reports a clean check-mark.
    - experiment.html: display_health + display_abort cases.
    - leader: _hb_diagnose() locali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
    [displayd.py, leader.py]
2026-08-24 Phase 4: stop the spurious display alarms, guard the X footgun
    Three defects that were harmless while nothing consumed displayd's
    alarms, and became false pages the moment they reached Slack.
    - renderer: remove PR_SET_PDEATHSIG. On Linux it fires when the parent
    THREAD exits, not the process. displayd spawns renderers from the
    short-lived HTTP handler serving /bringup, so the kernel SIGTERMed
    every new renderer as soon as bringup returned: each bringup died
    once (rc=-15), raised renderer_died, and survived only on the
    supervisor's respawn. The getppid() watch was always the portable
    half and is now the whole guard (1 s, well inside the time a new
    displayd needs to reach its re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
    [displayd.py, renderer.py]
2026-08-24 Phase 4: port calibration to kmsdrm, delete the X path
    The last thing on the rig still needing X was geometry calibration.
    calib_geo turned out to be web-driven (Flask UI on :5091) with pygame
    only rendering, so the port is a backend swap, not a rewrite.
    - calib_geo.py: SDL pinned to kmsdrm at module scope (pygame is imported
    lazily inside run(), so that is early enough), DISPLAY dropped. Flask
    replaced by stdlib http.server: this must run on the SYSTEM python3
    (the conda env's SDL has no kmsdrm backend and silently falls back to
    a null driver), that interpreter has no Flask, and the Pis are
    firewall-gated — seven GET routes do not justify a dependency that
    strands whoever nex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
    [api.py, displayd.py]
2026-08-24 Phase 4: finish the KMS sweep — remaining tools, docs, UI resync
    Everything else that still assumed X, a display worker, or a follower
    process.
    - panel_grid.py, validate_calibration_pygame.py, dlp_color_test.py,
    sync_square_flash.py: SDL pinned to kmsdrm, DISPLAY dropped, usage
    lines moved to /usr/bin/python3. cal_start.sh launches the first two,
    so they would have failed the same way calib_geo did.
    - validate_calibration.py, display_test_patches.py: marked LEGACY in
    their docstrings — PsychoPy, needs X, neither is installed on the
    follower. Kept for reference, no longer look like live tools.
    - refresh_hz 60 -> 57.46 in the DLP rig configs. It only paced the
    non-vsync fallba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
    [leader.py, sync_square_flash.py]
2026-08-24 teensy: one TTL edge per flash, not per DLP colour sub-pulse
    Measured on the rig (DEBUG capture, 58k samples @4.8 kHz, every_n=5):
    one sync-square frame produces FOUR optical sub-pulses spaced 4.34 ms
    (230 Hz red segment rate), spanning ~14 ms; flashes repeat every 87.0 ms
    (= 5/57.46, confirmed). HOLDOFF_US was 5000 — inside that 4.34 ms train
    — so it accepted sub-pulses 1 and 3 and dropped 2 and 4: two edges per
    flash, purely by accident of 5 ms vs 4.34 ms.
    That masked failure. devices/photodiode.py's init verify is
    "missing-only" (detected >= emitted - 1), so at 2 edges/flash HALF the
    flashes could fail and the count still passed.
    HOLDOFF_US 5000 -> 30000. Constraint: sub-pulse train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
    [photodiode_sync_v2_1.ino, photodiode_sync_v2_2.ino]
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2026-08-24 Install builds a KMS Pi; Deploy actually reloads displayd
    Two "is it fresh?" gaps. Both would have bitten a rebuilt rig.
    INSTALL was still building the pre-migration stack:
    - wrote config_dlp.txt (FKMS) as the boot config plus an Xorg
    modesetting binding, and installed xserver-xorg*. A freshly installed
    follower would have come up on FKMS with X — the exact combination
    phase 4 removed, and X takes DRM master from displayd's renderer.
    Now writes dlp/sample_config/config_kms.txt as the ACTIVE config
    (verified byte-identical to what the working rig boots), removes any
    stale /etc/X11/xorg.conf, keeps FKMS as config_fkms_backup.txt, and
    installs no X packages.
    - installed display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
    [api.py]
2026-08-24 leader: record onset_ack_latency_s (SHOW -> flip) per trial
    display_latency_s is SHOW -> photons, which conflates the command path
    with the projector pipeline. displayd already reports the renderer's
    REAL flip time for each stimulus on the ack port and the leader already
    receives it (_note_onset_ack) — it just threw it away unless the
    photodiode had failed, so the split could only be inferred by
    subtracting a separately measured constant.
    Now recorded per trial:
    onset_ack_latency_s = SHOW -> flip (command path)
    display_latency_s - onset_ack_latency_s = flip -> photons (projector)
    Read at TRIAL END, not at the onset decision: the ack lands
    asynchronously and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
    [leader.py]
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2026-09-07 display: dither before the panel's 6-bit truncation
    The DPI link is RGB666, so the hardware drops the low 2 bits of every
    value we write. C(az) spans ~5:1, which is ~150 8-bit codes across the
    screen but only ~38 on the wire -- the luminance correction rendered as
    75 vertical columns, one of them 317 px wide.
    Add an 8x8 ordered dither at the single quantization point both field
    and patch surfaces now share. Offset is [0,step), not +/-step/2, because
    the panel truncates rather than rounds; the centred version de-bands but
    leaves the floor's systematic half-step darkening in place.
    Measured on the live warp map at bg 0.75: 8x8 block-mean error 2.045 ->
    0.061 code units, median band width 8 p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
    [display.py, dither_check.py]
2026-09-07 display_diagnostics: before/after renders of the panel dither
    Reproduces the RGB666 truncation from a real warp map and writes the
    frames, a 1:1 crop of the worst band, and a mid-row profile. The crop
    also carries a contrast-stretched pair, labelled as a visualisation:
    a 4-code step is nearly invisible in an sRGB PNG, so the plain render
    understates what the projector shows.
    Renders are gitignored; regenerate with the script.
    [dither_preview.py]
2026-09-07 dither_check: verify delivered contrast, not just the field
    The existing metrics ask whether ONE surface is smooth and at the right
    level. The paradigm depends on a different quantity: the gap between the
    patch and its background. Those come apart -- in mode 'none' the field is
    flat, bands not at all, and scores 0.000, while delivered contrast at
    0.15 is 27.7% wrong because patch and background land on the 4-code grid
    independently.
    Reference is the ACHIEVABLE contrast: a 6-bit ladder tops out at 252, so
    frac=1.0 is not representable and comparing against the nominal value
    would fail the panel for being a panel. Against the honest ceiling,
    truncation at full contrast is +7.2%, not the +2.1%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
    [display.py, dither_check.py]
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2026-09-08 controller: per-rig registry, one UDP demux, experiment blueprint (multi-rig phase 1)
    The controller held ONE rig in module globals and its UDP listener discarded the
    sender address, so a second rig's events were silently dropped. This adds the
    controller/ package that replaces app/ (setup/ follows in phase 2):
    - registry.py: a RigState per loaded rig (phase, session, trials, teardown lock,
    per-rig Slack webhook, per-rig SSE subscribers, per-rig log file) and the
    RigRegistry that maps Pi IPs back to rigs.
    - events.py: the one listening socket on 5571, opened once at start-up, sorting
    each datagram by sender IP and falling back to the `rig` field the leader now
    stamps on every event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
    [controller.example.yaml]
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2026-09-09 per-rig calibration folders, Pi-side rig fix, docs for the four-tab controller (multi-rig phase 4)
    - display_calibration/<rig>/ holds a rig's geometry, warp map and luminance files once
    tools/migrate_calibration_dir.py <rig> has run; compute_warp_map.py gains --cal-dir and
    fit_luminance_correction.py set_cal_dir() so the controller can point them there.
    - calib_geo.py reports a saved geometry to the URL given by --mac-url (the per-rig
    /api/rigs/<rig>/setup/receive_geometry), which cal_start.sh passes from $CAL_MAC_URL;
    no more hard-coded :4999.
    - pi_api reward calibration reads rigs/<rig>.yaml named in the request (else the newest
    rig file) instead of a hard-coded cheese.yaml.
    - .g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
    [api.py]
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2026-09-15 rigs: drop cheese.yaml; repoint every reference at cheddar
    The cheese rig is gone. Its YAML was also the tracked twin of the live
    cheddar config, so it was cited all over the repo as "the rig config":
    six docs, LEADER_WIRING (as the source of truth for the pins, with a
    link that would now dangle), two setup.html comments, the
    display_calibration README, the demo rig headers, a deprecated device's
    docstring and the .gitignore note beside cheddar.yaml.
    Point them at rigs/cheddar.yaml (noting it is untracked: it carries the
    Slack webhook) or at the generic rigs/<rig>.yaml. Also fixes the stale
    follower name (mozzarella -> cheddar-dlp) and records that cheddar's
    video_dir is a plain folder on t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
    [photodiode_filtered.py]
2026-09-15 controller: move settings to controller/configs/
    controller.yaml and its template controller.example.yaml now live in
    controller/configs/ instead of the repo root. On first load the
    controller moves a root-level controller.yaml into place (content and
    mode kept), so an existing checkout keeps its data root, groups and
    rsync path rather than starting over from the example. If the move
    fails the old file is read in place; if both exist the configs/ one
    wins and the old one is reported. Saves write their temp file beside
    the settings file, not at the repo root.
    .gitignore covers the new path, its temp files, and the old root path
    until it has been migrated. Docs point at the new location.
    Co-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
    [controller.example.yaml]
2026-09-15 Data tab: sessions without video, strict rsync, verified purge
    A date folder recorded with the camera unchecked has no video folder,
    so syncing it failed (rsync exit 23 on the video tree) and Sync &
    Poweroff never powered the rig off. The same code accepted exit 23/24
    as clean, which is also what an unreadable subdirectory gives, so
    uncopied files could be purged.
    - leader_data.py protocol 2: which trees hold each folder, camera_saved
    and camera_requested from the .h5 or metadata.yaml, missing_video, an
    optional data.video_mount, --folder scoping, and a purge that deletes
    only the trees the controller names with --verified.
    - sync.py: any nonzero rsync exit is an error, and per-file f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
    [_template.yaml, leader.py]
2026-09-15 shepherd: grace period for pi_api restarts; Install sets the time zone
    Every Deploy restarts pi_api, which is then unreachable for about 4 s,
    and shepherd paged "pi_api not responding" on the first failed probe, so
    each Deploy sent a false critical alert to Slack.
    - controller/pi_restart.py: Deploy (Experiment and Setup tabs) and
    Restart API time each pi_api restart and give the leader's shepherd
    the outage x1.5, kept within 5-60 s, through a new pi_api
    /api/shepherd_grace (shepherd/api_grace.json).
    - shepherd: api_health alerts only once pi_api has been away that long,
    10 s until the first timed restart; during a session it still alerts
    on the first failed probe. Stops promptly o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
    [api.py]
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2026-09-29 display_calibration: per-rig geometry/ and intensity/ folders + measured contrast cal
    - display_calibration/<rig>/{geometry,intensity}/ + <rig>/warp_map.npz (controller/calib_paths.py).
    cheddar gets the full geometry history and the Sep 8 intensity files; morbier gets the file its
    warp was built from this morning (a copy of cheddar's Sep 15 geometry, marked as such).
    - Dated geometry files are records: an edit saves a new rig_geometry_<now>.yaml and the rig
    points at it; Geometry Cal's Save also lands as a new dated file. Restored the Sep 15 file the
    old save path had rewritten.
    - Every warp build writes intensity/luminance_cal_<geostamp>_theoretical.yaml.
    - Contrast Cal (Setup): lig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
    [api.py, rig_geometry_20260929_1017.yaml]
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
